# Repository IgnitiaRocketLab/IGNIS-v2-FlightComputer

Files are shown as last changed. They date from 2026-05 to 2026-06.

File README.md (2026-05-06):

# IGNIS v2 — Flight Computer
### Ignitia Rocket Lab · Tecnológico de Monterrey GDL · LASC 2026

---

> *Designed to survive a rocket. Built by students who refused to buy one off the shelf.*

---

## What is this?

IGNIS v2 is the second generation SRAD (Student Researched and Developed) flight computer
for Ignitia Rocket Lab's entry in the **Latin American Space Challenge 2026**, held in Brazil.

It handles everything from liftoff to recovery — sensor fusion, apogee detection,
pyrotechnic deployment, real-time LoRa telemetry, and full flight data logging.
No commercial flight computer. No shortcuts.

---

## Hardware at a Glance

| Block | Component |
|---|---|
| MCU | ESP32-S3-WROOM-1-N8R8 |
| RF Telemetry | RFM95W — 915 MHz LoRa |
| Barometer | BMP180 |
| IMU | MPU-6050 (6-DOF) |
| Temp / Humidity | SHT40 |
| GPS | Adafruit GPS Breakout |
| Storage | MicroSD — SPI |
| Power | Dual AMS1117 series · VBAT → 5V → 3.3V |
| Pyro | 2-channel MOSFET deployment |
| PCB | 4-layer · Altium Designer · JLCPCB fab |
| Target apogee | 1,000 m — LASC Rocket Challenge |

---

## Project Structure

```
IGNIS-v2-FlightComputer/
├── Schematics/
│   ├── Main.SchDoc
│   ├── Power.SchDoc
│   ├── MCU.SchDoc
│   ├── RF_LoRa.SchDoc
│   ├── Sensors.SchDoc
│   ├── GPS.SchDoc
│   ├── Storage.SchDoc
│   ├── Indicators.SchDoc
│   └── Pyro.SchDoc
├── PCB/
│   └── IGNIS_v2.PcbDoc
├── Libraries/
└── Fabrication/
```

---

## Design & Development

**Lead Designer & Author** — [Emilio Guadarrama](https://github.com/Emilio-Guadarrama)  
Vice President, Ignitia Rocket Lab · Avionics & Electronics Lead

**Pyro Circuit** — Aristoteles Prieto  
**Team President** — Maximiliano Funoy Serrano  
**Faculty Advisor** — Dr. José Luis Henríquez Mercado

## Team

**Ignitia Rocket Lab**
Tecnológico de Monterrey — Campus Guadalajara

📧 ignitia.rocketlab@gmail.com

---

*IGNIS v2 is a fully student-designed system.
Every trace routed, every component chosen, every test run — by the team.*

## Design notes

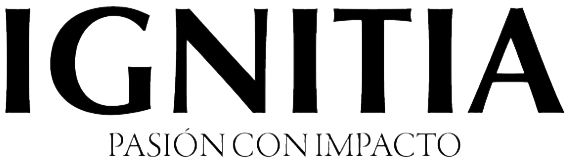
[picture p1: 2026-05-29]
PCB_Project_IGNIS-v2/Images/Firma_Ignitia.png

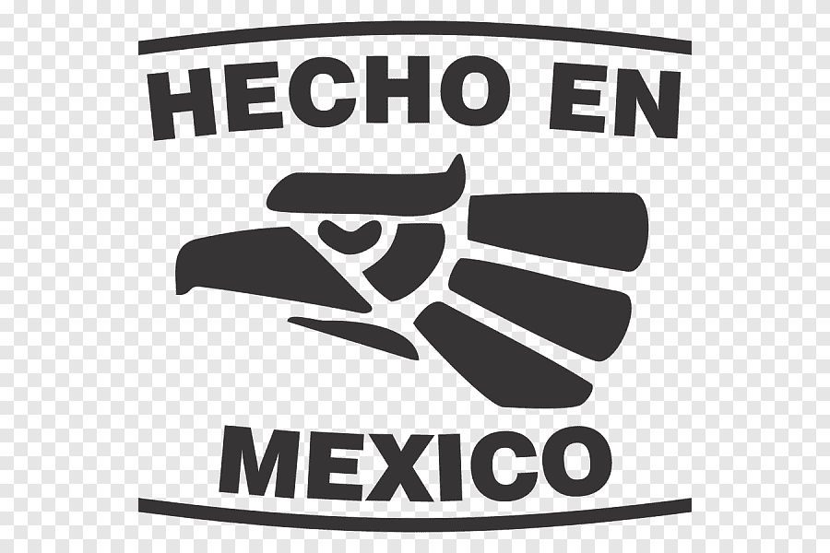
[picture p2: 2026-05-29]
PCB_Project_IGNIS-v2/Images/hecho en mx.png

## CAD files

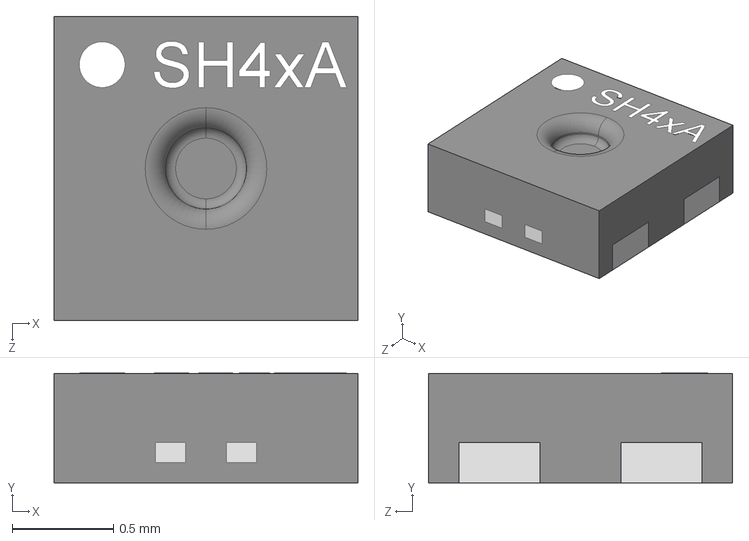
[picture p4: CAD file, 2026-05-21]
PCB_Project_IGNIS-v2/Components/Humidity and Temperature - SHT40-AD1B-R3/SHT40-AD1B-R3.STEP
1.50 x 0.541 x 1.50 mm

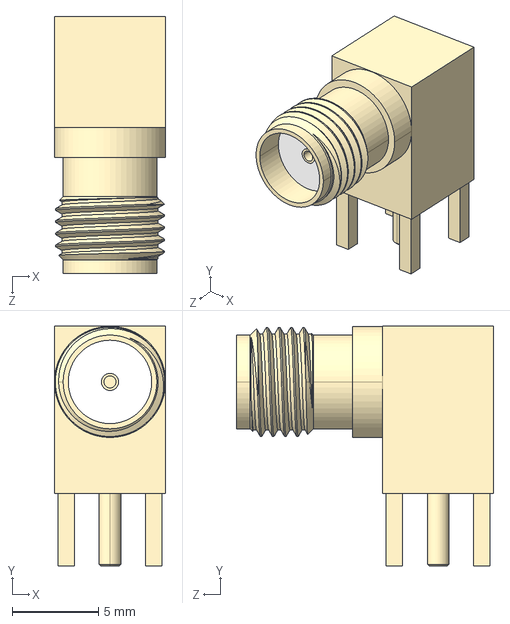
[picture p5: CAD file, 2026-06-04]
PCB_Project_IGNIS-v2/Components/SMA port - BWSMA-KE-Z001/SMA3D.STEP
6.46 x 13.9 x 15.0 mm

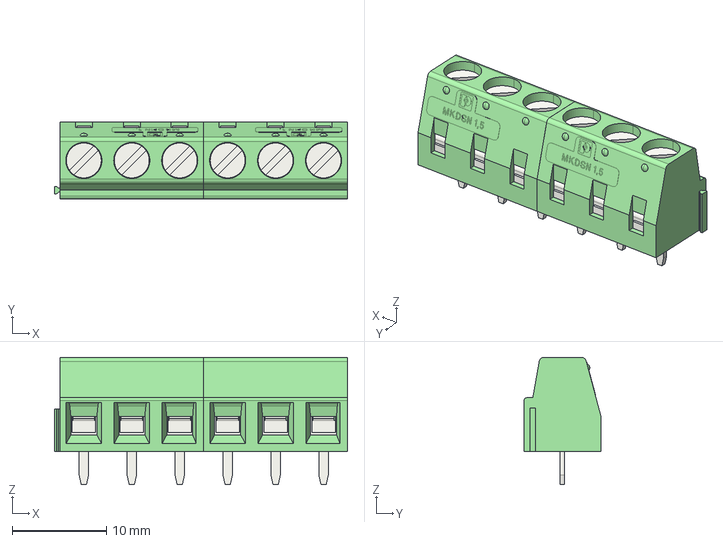
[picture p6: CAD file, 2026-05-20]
PCB_Project_IGNIS-v2/Components/Terminal Screw 5.08mm 16AWG (6 pin)/1729160.stp
31.0 x 8.15 x 13.5 mm

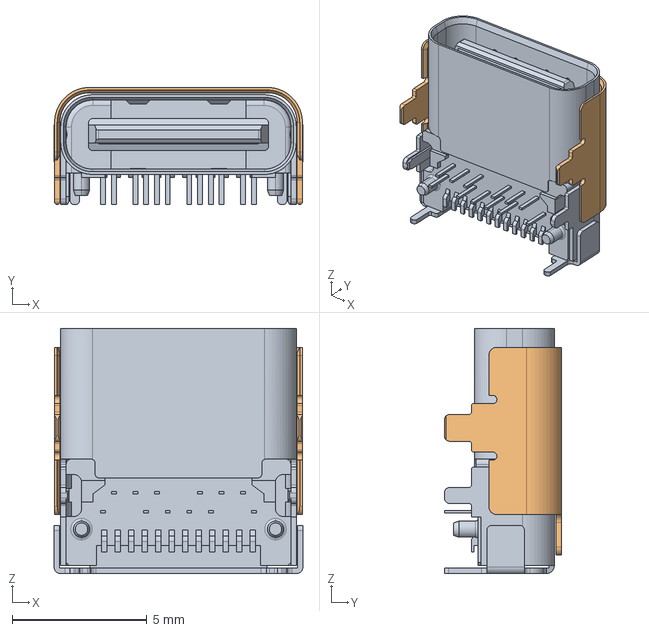
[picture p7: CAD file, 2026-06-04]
PCB_Project_IGNIS-v2/Components/USB-C Port 2/2338792-1--3DModel-STEP-78480.STEP
9.24 x 4.35 x 9.10 mm

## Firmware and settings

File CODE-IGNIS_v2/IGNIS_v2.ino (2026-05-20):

// ============================================================
//  IGNIS v2 — Flight Computer Firmware
//  Ignitia Rocket Lab | Tecnológico de Monterrey GDL
//  LASC 2026 — Rocket Challenge
//
//  Author:  Emilio Guadarrama Gutiérrez
//  Board:   ESP32-S3-WROOM-1-N16R8
//  IDE:     Arduino IDE 2.x
//  Target:  1,000 m apogee — dual-event pyrotechnic recovery
// ============================================================

// ============================================================
//  REQUIRED LIBRARIES
//  Install via Arduino Library Manager:
//    - RH_RF95 (RadioHead)         → LoRa RFM95W
//    - Adafruit BMP085 Unified     → BMP180 barometer
//    - Adafruit MPU6050            → IMU
//    - Adafruit SHT4x              → Temp/Humidity
//    - TinyGPSPlus                 → GPS parsing
//    - SD (built-in)               → MicroSD
//    - Adafruit NeoPixel           → WS2812B LEDs
//    - Wire, SPI (built-in)
// ============================================================

#include <Arduino.h>
#include <Wire.h>
#include <SPI.h>

// LoRa
#include <RH_RF95.h>

// Sensors
#include <Adafruit_BMP085.h>
#include <Adafruit_MPU6050.h>
#include <Adafruit_SHT4x.h>

// GPS
#include <TinyGPSPlus.h>
#include <HardwareSerial.h>

// Storage
#include <SD.h>

// LEDs
#include <Adafruit_NeoPixel.h>

// Sleep
#include <esp_sleep.h>

// ============================================================
//  PIN DEFINITIONS — match MCU.SchDoc net labels exactly
// ============================================================

// Pyro channels
#define PIN_PYRO_CH1_CONT   1   // IO1 — Channel 1 continuity sense
#define PIN_PYRO_CH1_GATE   4   // IO4 — Channel 1 fire gate
#define PIN_PYRO_CH2_CONT   2   // IO2 — Channel 2 continuity sense
#define PIN_PYRO_CH2_GATE   5   // IO5 — Channel 2 fire gate

// Battery monitoring
#define PIN_VBAT_MON        3   // IO3 — ADC (100k+47k divider)

// LoRa RFM95W (SPI)
#define PIN_RFM95W_CS       10  // IO10
#define PIN_RFM95W_INT      7   // IO7  — DIO0
#define PIN_RFM95W_RESET    8   // IO8

// SPI bus (shared: LoRa + MicroSD)
#define PIN_SPI_MOSI        11  // IO11
#define PIN_SPI_MISO        13  // IO13
#define PIN_SPI_SCK         12  // IO12

// MicroSD
#define PIN_SD_CS           14  // IO14
#define PIN_SD_DETECT       15  // IO15

// I2C bus (BMP180 + MPU6050 + SHT40)
#define PIN_I2C_SDA         8   // IO8  — shared with RFM95W_RESET via net SNS_I2C_SDA
#define PIN_I2C_SCL         9   // IO9

// GPS UART
#define PIN_GPS_TX          17  // IO17 — FC TX → GPS RX
#define PIN_GPS_RX          18  // IO18 — FC RX ← GPS TX

// Indicators
#define PIN_WS2812B         6   // IO6
#define PIN_BUZZER          16  // IO16

// Buttons (input only — handled by boot sequence)
#define PIN_BOOT            0   // IO0 — wake from sleep
#define PIN_MPU6050_INT     4   // IO4 — reused carefully

// USB
#define PIN_USB_DP          20  // IO20
#define PIN_USB_DN          19  // IO19

// ============================================================
//  CONFIGURATION
// ============================================================

// LoRa
#define LORA_FREQ           915.0
#define LORA_SF             9
#define LORA_BW             125000
#define LORA_CR             5       // 4/5
#define LORA_SYNC           0x12
#define LORA_TX_POWER       17      // PA_BOOST pin

// Flight parameters
#define LAUNCH_DETECT_ACCEL     2.0f    // g — min accel to detect launch
#define APOGEE_CONFIRM_COUNT    10      // consecutive descending readings
#define MAIN_DEPLOY_ALT         450.0f  // m AGL — main chute altitude
#define PYRO_FIRE_DURATION      1000    // ms — how long to hold gate HIGH
#define CONTINUITY_THRESHOLD    512     // ADC value to confirm e-match continuity

// Telemetry
#define TELEM_INTERVAL_MS       500     // ms between LoRa packets in flight
#define TELEM_INTERVAL_IDLE_MS  2000    // ms between packets on ground

// SD logging
#define LOG_INTERVAL_MS         100     // ms between SD writes in flight

// Battery
#define VBAT_DIVIDER_RATIO      (147.0f / 47.0f)  // (R5+R6)/R5 = 147k/47k
#define VBAT_ADC_REF            3.3f
#define VBAT_ADC_MAX            4095.0f
#define VBAT_LOW_THRESHOLD      6.8f    // V — warn below this

// LEDs
#define NUM_LEDS                3
#define LED_BRIGHTNESS          50

// ============================================================
//  FLIGHT STATE MACHINE
// ============================================================

enum FlightState {
  STATE_STANDBY,    // On rail — light sleep, waiting for ARM button
  STATE_ARMED,      // Sensors active, logging ready, awaiting launch
  STATE_FLIGHT,     // Powered ascent / coasting — detecting apogee
  STATE_APOGEE,     // Apogee detected — firing drogue (CH1)
  STATE_DESCENT,    // Descending — monitoring for main deploy altitude
  STATE_MAIN,       // Main deployed (CH2 fired)
  STATE_LANDED      // Below threshold velocity — beeping for recovery
};

FlightState flightState = STATE_STANDBY;

// ============================================================
//  GLOBAL OBJECTS
// ============================================================

RH_RF95          lora(PIN_RFM95W_CS, PIN_RFM95W_INT);
Adafruit_BMP085  bmp;
Adafruit_MPU6050 mpu;
Adafruit_SHT4x   sht;
TinyGPSPlus      gps;
HardwareSerial   gpsSerial(1);
Adafruit_NeoPixel leds(NUM_LEDS, PIN_WS2812B, NEO_GRB + NEO_KHZ800);

File logFile;
String logFileName = "/flight_000.csv";

// ============================================================
//  FLIGHT DATA STRUCT
// ============================================================

struct FlightData {
  // Time
  unsigned long timestamp_ms;

  // Barometer
  float altitude_m;
  float pressure_hpa;
  float temp_bmp_c;

  // IMU
  float accel_x, accel_y, accel_z;   // g
  float gyro_x,  gyro_y,  gyro_z;    // deg/s
  float total_accel_g;

  // Temp/Humidity
  float temp_sht_c;
  float humidity_pct;

  // GPS
  float lat, lon;
  float gps_alt_m;
  float gps_speed_ms;
  uint8_t gps_sats;
  bool  gps_valid;

  // Power
  float vbat_v;

  // Recovery
  bool ch1_continuity;
  bool ch2_continuity;

  // State
  FlightState state;
};

FlightData current;

// ============================================================
//  APOGEE DETECTION
// ============================================================

float groundAltitude_m    = 0.0f;
float peakAltitude_m      = 0.0f;
int   apogeeConfirmCount  = 0;
float lastAltitude_m      = 0.0f;
bool  launchDetected      = false;

// ============================================================
//  TIMING
// ============================================================

unsigned long lastTelemMs   = 0;
unsigned long lastLogMs     = 0;
unsigned long lastSensorMs  = 0;
unsigned long pyro1FireTime = 0;
unsigned long pyro2FireTime = 0;
bool pyro1Active = false;
bool pyro2Active = false;

// ============================================================
//  SETUP
// ============================================================

void setup() {
  Serial.begin(115200);
  delay(500);
  Serial.println("\n[IGNIS v2] Boot");

  // Pin modes
  pinMode(PIN_PYRO_CH1_GATE, OUTPUT);
  pinMode(PIN_PYRO_CH2_GATE, OUTPUT);
  pinMode(PIN_PYRO_CH1_CONT, INPUT);
  pinMode(PIN_PYRO_CH2_CONT, INPUT);
  digitalWrite(PIN_PYRO_CH1_GATE, LOW);
  digitalWrite(PIN_PYRO_CH2_GATE, LOW);

  pinMode(PIN_BUZZER, OUTPUT);
  pinMode(PIN_SD_DETECT, INPUT_PULLUP);
  pinMode(PIN_BOOT, INPUT_PULLUP);

  // LEDs
  leds.begin();
  leds.setBrightness(LED_BRIGHTNESS);
  setLED(0, 50, 50, 0);   // Yellow = booting

  // I2C
  Wire.begin(PIN_I2C_SDA, PIN_I2C_SCL);

  // SPI
  SPI.begin(PIN_SPI_SCK, PIN_SPI_MISO, PIN_SPI_MOSI);

  // BMP180
  if (!bmp.begin()) {
    Serial.println("[ERROR] BMP180 not found");
    errorHalt();
  }
  Serial.println("[OK] BMP180");

  // MPU6050
  if (!mpu.begin()) {
    Serial.println("[ERROR] MPU6050 not found");
    errorHalt();
  }
  mpu.setAccelerometerRange(MPU6050_RANGE_8_G);
  mpu.setGyroRange(MPU6050_RANGE_500_DEG);
  mpu.setFilterBandwidth(MPU6050_BAND_21_HZ);
  Serial.println("[OK] MPU6050");

  // SHT40
  if (!sht.begin()) {
    Serial.println("[ERROR] SHT40 not found");
    // Non-fatal — continue without it
  } else {
    sht.setPrecision(SHT4X_HIGH_PRECISION);
    Serial.println("[OK] SHT40");
  }

  // GPS — low power until needed
  gpsSerial.begin(9600, SERIAL_8N1, PIN_GPS_RX, PIN_GPS_TX);
  Serial.println("[OK] GPS UART");

  // RFM95W
  initLoRa();

  // MicroSD
  initSD();

  // Calibrate ground altitude
  calibrateGroundAltitude();

  // Battery check
  float vbat = readVbat();
  Serial.printf("[VBAT] %.2f V\n", vbat);
  if (vbat < VBAT_LOW_THRESHOLD) {
    Serial.println("[WARN] Battery low!");
    buzz(100); delay(100); buzz(100);
  }

  // Boot complete
  setLED(0, 0, 0, 50);  // Blue = standby
  buzz(200);
  Serial.println("[IGNIS v2] Ready — entering STANDBY");
  flightState = STATE_STANDBY;
}

// ============================================================
//  MAIN LOOP
// ============================================================

void loop() {
  unsigned long now = millis();

  // Read sensors every 50ms
  if (now - lastSensorMs >= 50) {
    readAllSensors();
    lastSensorMs = now;
  }

  // State machine
  switch (flightState) {

    case STATE_STANDBY:
      // Light sleep — wake on BOOT button press to arm
      handleStandby();
      break;

    case STATE_ARMED:
      handleArmed(now);
      break;

    case STATE_FLIGHT:
      handleFlight(now);
      break;

    case STATE_APOGEE:
      handleApogee(now);
      break;

    case STATE_DESCENT:
      handleDescent(now);
      break;

    case STATE_MAIN:
      handleMain(now);
      break;

    case STATE_LANDED:
      handleLanded(now);
      break;
  }

  // Manage active pyro channels
  managePyroChannels(now);

  // Log to SD
  if (flightState >= STATE_ARMED && now - lastLogMs >= LOG_INTERVAL_MS) {
    logToSD();
    lastLogMs = now;
  }

  // Telemetry
  unsigned long telemInterval = (flightState >= STATE_FLIGHT)
                                ? TELEM_INTERVAL_MS
                                : TELEM_INTERVAL_IDLE_MS;
  if (now - lastTelemMs >= telemInterval) {
    sendTelemetry();
    lastTelemMs = now;
  }
}

// ============================================================
//  STATE HANDLERS
// ============================================================

void handleStandby() {
  // ⚠️ FIRMWARE REMINDER: Rail standby — 4 hour requirement
  // ESP32-S3 must be in light sleep here
  // GPS must stay in backup mode — not actively acquiring
  // Wake only on BOOT button press

  Serial.println("[STANDBY] Sleeping... press BOOT to arm");

  // Configure wake-up source
  esp_sleep_enable_ext0_wakeup((gpio_num_t)PIN_BOOT, 0);  // Wake on LOW

  // GPS to sleep
  gpsSerial.println("$PMTK161,0*28");  // GPS standby command

  // LED off to save power
  setLED(0, 0, 0, 0);

  // Enter light sleep
  esp_light_sleep_start();

  // Woke up — check if BOOT button caused wake
  if (esp_sleep_get_wakeup_cause() == ESP_SLEEP_WAKEUP_EXT0) {
    Serial.println("[STANDBY] BOOT pressed — ARMING");
    transitionTo(STATE_ARMED);
  }
}

void handleArmed(unsigned long now) {
  setLED(0, 50, 0, 0);   // Red = armed

  // Check continuity
  current.ch1_continuity = (analogRead(PIN_PYRO_CH1_CONT) > CONTINUITY_THRESHOLD);
  current.ch2_continuity = (analogRead(PIN_PYRO_CH2_CONT) > CONTINUITY_THRESHOLD);

  if (!current.ch1_continuity) Serial.println("[WARN] CH1 continuity FAIL");
  if (!current.ch2_continuity) Serial.println("[WARN] CH2 continuity FAIL");

  // Detect launch: sustained high acceleration
  if (current.total_accel_g >= LAUNCH_DETECT_ACCEL) {
    if (!launchDetected) {
      launchDetected = true;
      Serial.printf("[LAUNCH] Detected! Accel=%.2fg\n", current.total_accel_g);
      transitionTo(STATE_FLIGHT);
    }
  }
}

void handleFlight(unsigned long now) {
  setLED(0, 0, 50, 0);  // Green = flight

  float alt = current.altitude_m - groundAltitude_m;

  // Track peak altitude
  if (alt > peakAltitude_m) {
    peakAltitude_m = alt;
    apogeeConfirmCount = 0;
  }

  // Apogee detection: altitude consistently decreasing
  if (alt < lastAltitude_m) {
    apogeeConfirmCount++;
  } else {
    apogeeConfirmCount = 0;
  }
  lastAltitude_m = alt;

  if (apogeeConfirmCount >= APOGEE_CONFIRM_COUNT) {
    Serial.printf("[APOGEE] Detected at %.1f m AGL\n", peakAltitude_m);
    transitionTo(STATE_APOGEE);
  }
}

void handleApogee(unsigned long now) {
  setLED(50, 0, 50, 0);  // Magenta = apogee

  // Fire drogue — Channel 1
  if (!pyro1Active) {
    Serial.println("[PYRO] Firing CH1 — DROGUE");
    firePyro(1);
  }

  // Once pyro fires, transition to descent
  if (!pyro1Active && now - pyro1FireTime > PYRO_FIRE_DURATION + 100) {
    transitionTo(STATE_DESCENT);
  }
}

void handleDescent(unsigned long now) {
  setLED(0, 50, 50, 0);  // Cyan = descent

  float agl = current.altitude_m - groundAltitude_m;

  Serial.printf("[DESCENT] AGL=%.1f m\n", agl);

  // Main deployment at 450m AGL
  if (agl <= MAIN_DEPLOY_ALT && !pyro2Active) {
    Serial.printf("[PYRO] Firing CH2 — MAIN at %.1f m AGL\n", agl);
    firePyro(2);
    transitionTo(STATE_MAIN);
  }
}

void handleMain(unsigned long now) {
  setLED(0, 0, 50, 50);  // White-ish = main deployed

  // Wait for landing: low altitude + near-zero vertical speed
  float agl = current.altitude_m - groundAltitude_m;
  if (agl < 20.0f && current.total_accel_g < 1.2f) {
    Serial.println("[LANDED] Touchdown detected");
    transitionTo(STATE_LANDED);
  }
}

void handleLanded(unsigned long now) {
  // Beep for recovery every 2 seconds
  static unsigned long lastBeep = 0;
  if (now - lastBeep >= 2000) {
    buzz(100);
    setLED(50, 50, 50, 0);
    delay(50);
    setLED(0, 0, 0, 0);
    lastBeep = now;
  }

  // Close SD log file
  if (logFile) {
    logFile.close();
    Serial.println("[SD] Log file closed");
  }
}

// ============================================================
//  PYRO CONTROL
// ============================================================

void firePyro(int channel) {
  if (channel == 1) {
    digitalWrite(PIN_PYRO_CH1_GATE, HIGH);
    pyro1FireTime = millis();
    pyro1Active = true;
    Serial.println("[PYRO] CH1 gate OPEN");
    buzz(500);
  } else if (channel == 2) {
    digitalWrite(PIN_PYRO_CH2_GATE, HIGH);
    pyro2FireTime = millis();
    pyro2Active = true;
    Serial.println("[PYRO] CH2 gate OPEN");
    buzz(500);
  }
}

void managePyroChannels(unsigned long now) {
  if (pyro1Active && now - pyro1FireTime >= PYRO_FIRE_DURATION) {
    digitalWrite(PIN_PYRO_CH1_GATE, LOW);
    pyro1Active = false;
    Serial.println("[PYRO] CH1 gate CLOSED");
  }
  if (pyro2Active && now - pyro2FireTime >= PYRO_FIRE_DURATION) {
    digitalWrite(PIN_PYRO_CH2_GATE, LOW);
    pyro2Active = false;
    Serial.println("[PYRO] CH2 gate CLOSED");
  }
}

// ============================================================
//  SENSOR READING
// ============================================================

void readAllSensors() {
  current.timestamp_ms = millis();

  // BMP180
  current.pressure_hpa = bmp.readPressure() / 100.0f;
  current.temp_bmp_c   = bmp.readTemperature();
  current.altitude_m   = bmp.readAltitude(1013.25f);  // Update with QNH if available

  // MPU6050
  sensors_event_t accel_evt, gyro_evt, temp_evt;
  mpu.getEvent(&accel_evt, &gyro_evt, &temp_evt);
  current.accel_x = accel_evt.acceleration.x / 9.81f;
  current.accel_y = accel_evt.acceleration.y / 9.81f;
  current.accel_z = accel_evt.acceleration.z / 9.81f;
  current.gyro_x  = gyro_evt.gyro.x * RAD_TO_DEG;
  current.gyro_y  = gyro_evt.gyro.y * RAD_TO_DEG;
  current.gyro_z  = gyro_evt.gyro.z * RAD_TO_DEG;
  current.total_accel_g = sqrt(
    current.accel_x * current.accel_x +
    current.accel_y * current.accel_y +
    current.accel_z * current.accel_z
  );

  // SHT40
  sensors_event_t hum_evt, temp_sht_evt;
  sht.getEvent(&hum_evt, &temp_sht_evt);
  current.temp_sht_c  = temp_sht_evt.temperature;
  current.humidity_pct = hum_evt.relative_humidity;

  // GPS
  while (gpsSerial.available()) {
    gps.encode(gpsSerial.read());
  }
  if (gps.location.isValid()) {
    current.lat       = gps.location.lat();
    current.lon       = gps.location.lng();
    current.gps_alt_m = gps.altitude.meters();
    current.gps_speed_ms = gps.speed.mps();
    current.gps_sats  = gps.satellites.value();
    current.gps_valid = true;
  } else {
    current.gps_valid = false;
  }

  // Battery
  current.vbat_v = readVbat();
}

float readVbat() {
  int raw = analogRead(PIN_VBAT_MON);
  float vPin = (raw / VBAT_ADC_MAX) * VBAT_ADC_REF;
  return vPin * VBAT_DIVIDER_RATIO;
}

void calibrateGroundAltitude() {
  Serial.println("[CAL] Calibrating ground altitude...");
  float sum = 0;
  for (int i = 0; i < 20; i++) {
    sum += bmp.readAltitude(1013.25f);
    delay(50);
  }
  groundAltitude_m = sum / 20.0f;
  Serial.printf("[CAL] Ground = %.1f m\n", groundAltitude_m);
}

// ============================================================
//  LORA TELEMETRY
// ============================================================

void initLoRa() {
  pinMode(PIN_RFM95W_RESET, OUTPUT);
  digitalWrite(PIN_RFM95W_RESET, LOW);
  delay(10);
  digitalWrite(PIN_RFM95W_RESET, HIGH);
  delay(10);

  if (!lora.init()) {
    Serial.println("[ERROR] RFM95W init failed");
    errorHalt();
  }

  lora.setFrequency(LORA_FREQ);
  lora.setTxPower(LORA_TX_POWER, false);  // false = PA_BOOST pin
  lora.setSpreadingFactor(LORA_SF);
  lora.setSignalBandwidth(LORA_BW);
  lora.setCodingRate4(LORA_CR);
  lora.setSyncWord(LORA_SYNC);

  Serial.printf("[OK] RFM95W @ %.1f MHz SF%d\n", LORA_FREQ, LORA_SF);
}

void sendTelemetry() {
  // Build compact CSV packet
  char packet[120];
  snprintf(packet, sizeof(packet),
    "%lu,%d,%.1f,%.1f,%.2f,%.2f,%.2f,%.2f,%.6f,%.6f,%d,%.2f,%d,%d",
    current.timestamp_ms,
    (int)flightState,
    current.altitude_m - groundAltitude_m,  // AGL
    peakAltitude_m,
    current.total_accel_g,
    current.pressure_hpa,
    current.temp_bmp_c,
    current.vbat_v,
    current.lat,
    current.lon,
    current.gps_sats,
    current.gps_alt_m,
    current.ch1_continuity ? 1 : 0,
    current.ch2_continuity ? 1 : 0
  );

  lora.send((uint8_t*)packet, strlen(packet));
  lora.waitPacketSent();

  // Read RSSI accurately — SX1276 HF port offset = -157
  // Do NOT use lora.lastRssi() — it uses wrong -137 offset
  // Requires direct SPI register read if using RadioHead
  // For RadioLib: use spiRead(0x1A) - 157
}

// ============================================================
//  SD CARD LOGGING
// ============================================================

void initSD() {
  if (!SD.begin(PIN_SD_CS)) {
    Serial.println("[WARN] SD card not found — logging disabled");
    return;
  }

  // Find available filename
  for (int i = 0; i < 999; i++) {
    logFileName = "/flight_" + String(i, DEC) + ".csv";
    if (!SD.exists(logFileName)) break;
  }

  logFile = SD.open(logFileName, FILE_WRITE);
  if (!logFile) {
    Serial.println("[WARN] Could not open log file");
    return;
  }

  // Write CSV header
  logFile.println(
    "timestamp_ms,state,alt_agl_m,peak_alt_m,"
    "accel_total_g,accel_x,accel_y,accel_z,"
    "gyro_x,gyro_y,gyro_z,"
    "pressure_hpa,temp_bmp_c,temp_sht_c,humidity_pct,"
    "vbat_v,lat,lon,gps_alt_m,gps_sats,"
    "ch1_cont,ch2_cont"
  );
  logFile.flush();

  Serial.printf("[SD] Logging to %s\n", logFileName.c_str());
}

void logToSD() {
  if (!logFile) return;

  logFile.printf(
    "%lu,%d,%.2f,%.2f,"
    "%.3f,%.3f,%.3f,%.3f,"
    "%.2f,%.2f,%.2f,"
    "%.2f,%.2f,%.2f,%.1f,"
    "%.3f,%.6f,%.6f,%.1f,%d,"
    "%d,%d\n",
    current.timestamp_ms,
    (int)flightState,
    current.altitude_m - groundAltitude_m,
    peakAltitude_m,
    current.total_accel_g,
    current.accel_x, current.accel_y, current.accel_z,
    current.gyro_x,  current.gyro_y,  current.gyro_z,
    current.pressure_hpa,
    current.temp_bmp_c,
    current.temp_sht_c,
    current.humidity_pct,
    current.vbat_v,
    current.lat, current.lon,
    current.gps_alt_m,
    current.gps_sats,
    current.ch1_continuity ? 1 : 0,
    current.ch2_continuity ? 1 : 0
  );

  // Flush every 10 writes to reduce SD wear
  static int writeCount = 0;
  if (++writeCount >= 10) {
    logFile.flush();
    writeCount = 0;
  }
}

// ============================================================
//  LED CONTROL
// ============================================================

void setLED(int r, int g, int b, int white) {
  for (int i = 0; i < NUM_LEDS; i++) {
    leds.setPixelColor(i, leds.Color(r, g, b));
  }
  leds.show();
}

// ============================================================
//  BUZZER
// ============================================================

void buzz(int duration_ms) {
  digitalWrite(PIN_BUZZER, HIGH);
  delay(duration_ms);
  digitalWrite(PIN_BUZZER, LOW);
}

// ============================================================
//  STATE TRANSITION
// ============================================================

void transitionTo(FlightState newState) {
  Serial.printf("[STATE] %d → %d\n", (int)flightState, (int)newState);
  flightState = newState;
  buzz(100);
}

// ============================================================
//  ERROR HALT
// ============================================================

void errorHalt() {
  Serial.println("[FATAL] System halted");
  while (true) {
    setLED(50, 0, 0, 0);
    buzz(200);
    delay(200);
    setLED(0, 0, 0, 0);
    delay(200);
  }
}

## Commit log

2026-05-06 wip: Power.SchDoc in progress — dual AMS1117, USB-C, SS24, VBAT_MON divider complete — R3/R4 pin connection issue pending
    [MCU.SchDoc, PCB_Project_IGNIS_v2.PrjPcb, Power.SchDoc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]
2026-05-06 wip: session end — library updates and Power.SchDoc latest state
    [MCU.SchDoc, Power.SchDoc]
2026-05-14 feat: MCU.SchDoc complete — ESP32-S3-N16R8, IO assignments, EN RC, buttons, I2C pull-ups
    [MCU.SchDoc, Power.SchDoc]
2026-05-20 Change in the Pyro Schematic and also I moved the pull down recistences of the communication
    [1729160.SchLib, 1729160.stp, MCU.SchDoc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]
2026-05-20 feat: add IGNIS_v2.ino — first version flight computer firmware
2026-05-21 feat: RF_LoRa and GPS sheet started — RFM95W and GPS blocks placed, I2C pull-ups moved to Sensors.SchDoc
    [Pyros.SchDoc, RF_LoRa_&_GPS.SchDoc, Sensors.SchDoc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]
2026-05-21 feat: update HumTemp-SHT40-AD1B-R3 library — added footprint, schematic symbol and 3D model
    [SHT40-AD1B-R3.STEP, SHT40-AD1B-R3.SchLib, SHT4X.PcbLib]
2026-05-21 Structural changes
    [MCU.SchDoc, Main.SchDoc, PCB_Project_IGNIS_v2.PrjPcb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]
2026-05-21 wip: Sensors.SchDoc, RF_LoRa_GPS.SchDoc in progress — components placed, nets labeled, BMP180 pins pending
    [BMP180.PcbLib, BMP180.SchLib, Main.SchDoc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]
2026-05-21 chore: reorganize project structure — PCB project at top level, libraries restructured
    [Storage.SchDoc]
2026-05-22 feat: Storage.SchDoc complete — MicroSD slot, SPI interface ports, pull-up network added
    [Main.SchDoc, Pyros.SchDoc, Storage.SchDoc]
2026-05-22 feat: Indicators.SchDoc complete — 3x WS2812B daisy-chain, S8050 buzzer driver, VCC_5V verified
    [BUZZER_CMI-1275C-050.SchLib, BUZZER_CUI_CMI-1275C-050.PcbLib, Indicators.SchDoc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]
2026-05-22 wip: schematic ERC cleanup in progress — 40 errors remaining, sheet scope set to automatic, Storage/Sensors/RF net labels pending
    [Main.SchDoc, RF_LoRa_&_GPS.SchDoc, Sensors.SchDoc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]
2026-05-22 fix: clean MicroSD SPI net naming and port directions
    [Main.SchDoc, PCB_Project_IGNIS_v2.PrjPcb, Storage.SchDoc]
2026-05-22 fix: resolve ERC errors and clean hierarchical power ports
    [Main.SchDoc, PCB_Project_IGNIS_v2.PrjPcb, Power.SchDoc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]
2026-05-22 docs: add PCB design document and clean ERC warnings
    [Main.SchDoc, PCB1_IGNIS_v2.PcbDoc, PCB_Project_IGNIS_v2.PrjPcb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]
2026-05-23 fix: clean ERC warnings
    [Antenna-RFM95W-868S2.SchLib, Main.SchDoc, PCB1_IGNIS_v2.PcbDoc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]
2026-05-23 fix: resolve all ERC errors and warnings — clean compile achieved
    [Main.SchDoc, PCB_Project_IGNIS_v2.PrjPcb, Sensors.SchDoc]
2026-05-24 layout: initial component placement and board outline 90x40mm
2026-05-25 Created initial lay out approach, proposal to be pulish
    [Main.SchDoc, PCB_Project_IGNIS_v2.PrjPcb, Power.SchDoc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]
2026-05-26 Few changes
    [Indicators.SchDoc, Power.SchDoc, Ultimate GPS.PcbLib]
2026-05-29 Perfected layout, resolved all DRC conflicts, wiring is misssing
    [1N4148W-7.SchLib, Indicators.SchDoc, LED_RGB-WS2812B.PcbLib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]
2026-05-29 layout: added Ignitia Rocket Lab logo to silkscreen
2026-05-29 Silk mask finished
    [LED_RGB_WS2812B.PcbLib]
2026-06-02 routing: complete 4-layer routing, impedance control, power pours, DRC clean 0 violations
    - 4-layer stackup configured (L1 Signal, L2 GND Pour, L3 VCC_3V3 Pour, L4 Signal)
    - RF antenna trace routed 6.8mil 50Ohm controlled impedance on L1
    - GND polygon pour L2, VCC_3V3 polygon pour L3, VBAT polygon L4
    - All polygon connect styles set to Direct Connect
    - USB DN/DP differential pair routed 6mil matched length
    - Pyro EMATCH traces 31mil direct connect to VBAT polygon
    - Signal vias 12mil hole 24mil pad, power vias 20mil hole 39mil pad
    - Mounting hole pads 126mil hole 197mil pad GND connected
    - DRC rules: clearance 4mil, RF width locked 6.8mil, VBAT direct connect
    - NetAntennae rule scoped to excl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
    [Main.SchDoc, PCB1_IGNIS_v2.PcbDoc]
2026-06-02 layout: GND polygon pours added L1 and L4, full copper fill all layers, DRC 0 violations
    [PCB1_IGNIS_v2.PcbDoc]
2026-06-02 fab: Gerbers, NC Drill, OutJob and ZIP generated for JLCPCB
    [PCB1_IGNIS_v2.PcbDoc, PCB_Project_IGNIS_v2.PrjPcb]
2026-06-04 refactor: rename PCB_Project_IGNIS-1 to IGNIS_v2, add Images folder
    [1729160.stp, 1N4148W-7.SchLib, 2338792-1--3DModel-STEP-78480.STEP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]
2026-07-13 Add manufacturing outputs for PCB v2 submission
    [PCB1_IGNIS_v2.GBL, PCB1_IGNIS_v2.GBO, PCB1_IGNIS_v2.GBP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]
2026-11-11 docs: add board photos, layer views and schematic to README
